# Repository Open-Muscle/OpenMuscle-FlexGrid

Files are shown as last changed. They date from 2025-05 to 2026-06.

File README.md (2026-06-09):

# 🧠 OpenMuscle-FlexGrid






OpenMuscle FlexGrid is a modular 60-sensor pressure-sensing platform designed for advanced forearm-based gesture tracking and biomechanical research.

This device is part of the [OpenMuscle](https://github.com/Open-Muscle) ecosystem and represents a leap forward from the original 12-sensor OM12 prototype by introducing high-density, flex-rigid PCBs and better sensor modularity.

### 📌 For documentation, firmware, and assembly guidance, visit the [OpenMuscle Hub](https://github.com/Open-Muscle/OpenMuscle-Hub).

---

## 🚀 Current revisions

**V4 (in development, 2026-06).** Ready for fab. Adds an on-device **microSD card socket** for local data logging, a **discrete RGB status LED** on three PWM channels, and a reoriented slimmer board profile that hugs the forearm. Carries forward the V3 power and interconnect architecture, but with the FFC tail width corrected from 11.1 mm to **10.5 mm** per the Wurth 687120183722 datasheet, the ADC matrix-row caps reduced from 2.2 uF to **100 pF** (resolves V3's 22 ms RC bleed in silicon rather than via post-fab cap removal), all resistors normalized to 0603, and several footprint cleanups. Manufacturing strategy: **single-side SMT at JLCPCB for an initial batch of 10 units, plus hand-soldering of bottom-side parts and through-hole connectors at home**. Not yet ordered, not yet brought up. Full status and pre-fab checklist in the [V4 README](KiCad/OM-FlexGrid%20V4/README.md).

**V3 (stable, 2026-05-13).** First revision to use a 20-pin ZIF FFC connector for the flex-to-rigid interconnect (Wurth 687120183722). Two boards populated and tested end-to-end. Sensor matrix delivers **clean single-cell press detection across all 60 sensors** with ~22% carryover decaying to noise floor within 3 columns. **V3 is the first FlexGrid generation usable as a real ML training data source.** Firmware: [FlexGridV3-Firmware v0.1.7](https://github.com/Open-Muscle/FlexGridV3-Firmware).

→ For V4 hardware files, see [`KiCad/OM-FlexGrid V4/`](KiCad/OM-FlexGrid%20V4/) and the [V4 README](KiCad/OM-FlexGrid%20V4/README.md). For V3 see [`KiCad/OM-FlexGrid V3/`](KiCad/OM-FlexGrid%20V3/) and the [V3 README](KiCad/OM-FlexGrid%20V3/README.md). The MicroPython firmware that runs on V3 (and will be ported to V4) lives at [FlexGridV3-Firmware](https://github.com/Open-Muscle/FlexGridV3-Firmware).

| Revision | Status | Notes |
|---|---|---|
| **V4** | 🟡 In development | microSD + RGB LED + slimmer reorient; 10.5 mm FFC tail; 100 pF ADC caps; not yet fabbed |
| **V3** | 🟢 Validated | 20-pin FFC interconnect, integrated stiffened FFC tail, ~140 Hz raw scan |
| V2 | 🟢 Tested | FFC connector exploration, fabric harness testing |
| V1 | 🟢 Tested | First production revision |
| V0 | 🟢 Tested | Original prototype |

→ Full cross-version comparison: [`KiCad/REVISIONS.md`](KiCad/REVISIONS.md). Manufacturing process used across revisions: [`docs/JLCPCB_WORKFLOW.md`](docs/JLCPCB_WORKFLOW.md).

---

## 🧬 Overview

FlexGrid uses a flexible pressure sensor matrix with rigid breakout interfaces to detect volumetric muscle contractions in real time. It supports:

- 🧠 Biomechanical signal analysis  
- 🦾 Prosthetics and exosuit research  
- 🎛️ Machine learning data pipelines  

---

## 📁 Hardware Design Files

Design files are organized by board type and version:

### 🔌 KiCad Schematics & PCB Layout

📂 [`KiCad/`](KiCad/) — all design files, organized by revision.

| Revision | Path | Description |
|---|---|---|
| **V4** (in dev) | [`KiCad/OM-FlexGrid V4/`](KiCad/OM-FlexGrid%20V4/) | microSD socket, RGB status LED, slimmer reorient, 10.5 mm FFC tail, 100 pF ADC caps. See [V4 README](KiCad/OM-FlexGrid%20V4/README.md). |
| **V3** (stable) | [`KiCad/OM-FlexGrid V3/`](KiCad/OM-FlexGrid%20V3/) | Validated. 20-pin ZIF FFC interconnect. See [V3 README](KiCad/OM-FlexGrid%20V3/README.md). |
| V2 | [`KiCad/OM-FlexGrid V2/`](KiCad/OM-FlexGrid%20V2/) | Tested. FFC exploration + fabric harness. See [V2 README](KiCad/OM-FlexGrid%20V2/README.md). |
| V1 | [`KiCad/OM-FlexGrid V1/`](KiCad/OM-FlexGrid%20V1/) | First production revision. |
| V0 | [`KiCad/OM-FlexGrid V0/`](KiCad/OM-FlexGrid%20V0/) | Original prototype. |

Each revision folder contains both the flex (`OM-FlexGrid-Flex/`) and rigid (`OM-FlexGrid-Rigid-PCB/`) board projects, plus their gerber bundles.

---

### 📦 Bill of Materials

BOMs live next to their KiCad project for each revision:

- **V4 Rigid (JLCPCB-ready):** [`KiCad/OM-FlexGrid V4/OM-FlexGrid-Rigid-PCB/jlcpcb/production_files/BOM-OM-FlexGrid-Rigid-PCB.csv`](KiCad/OM-FlexGrid%20V4/OM-FlexGrid-Rigid-PCB/jlcpcb/production_files/BOM-OM-FlexGrid-Rigid-PCB.csv) (LCSC part numbers, machine-readable, generated by the JLCPCB KiCad plugin). The hand-soldered parts list (microSD socket, FFC connector, battery JST, pin headers, plus single-side-strategy BOT-side SMT) is documented prose-style in the [V4 README](KiCad/OM-FlexGrid%20V4/README.md#hand-soldered-parts-full-list).
- **V3 Rigid:** [`KiCad/OM-FlexGrid V3/OM-FlexGrid-Rigid-PCB/OM-FlexGrid-Rigid-PCB.csv`](KiCad/OM-FlexGrid%20V3/OM-FlexGrid-Rigid-PCB/OM-FlexGrid-Rigid-PCB.csv) (KiCad export).
- **Flex (V3 and V4):** no electronic-component BOM. The flex tail integrates the FFC connector pads directly; the only off-board parts are the Velostat sheet and the mating Wurth 687120183722 connector populated on the rigid board.

Older revision BOMs are kept under [`BOM/`](BOM/) for history.

---

### 🛠 Assembly & Testing

Instructions for soldering, testing, and integrating the FlexGrid with ESP32-S3 firmware are in development. For now, please refer to the [OpenMuscle Hub](https://github.com/Open-Muscle/OpenMuscle-Hub) and follow updates on [YouTube Open Muscle](https://youtube.com/@openmuscle) or [TURFPTAx Youtube](https://youtube.com/@turfptax).

---

## 🤝 Contributions

We welcome improvements to sensor design, firmware, or real-world testing. Please fork the repo and submit pull requests!

---
**Open Muscle** is an open-source prosthetic sensor initiative designed for accessibility, innovation, and community collaboration.

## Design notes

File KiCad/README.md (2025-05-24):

"""
# FlexGrid KiCad Design Files

This folder contains the KiCad project files for the Open Muscle FlexGrid, a high-density, 60-sensor forearm band designed for advanced biometric data collection.

## 📁 Folder Contents

- `FlexGrid.kicad_pro` – KiCad project file  
- `FlexGrid.kicad_sch` – Schematic diagram  
- `FlexGrid.kicad_pcb` – PCB layout  
- `symbols/` – Custom schematic symbols  
- `footprints/` – Custom PCB footprints  
- `3dmodels/` – 3D models for components  
- `gerbers/` – Fabrication-ready Gerber files  
- `bom/` – Bill of Materials (CSV format)

## 🧠 About FlexGrid

FlexGrid is a 15x4 sensor matrix (totaling 60 sensors) integrated into a flexible PCB, utilizing an ESP32-S3 microcontroller for data acquisition and transmission. The design emphasizes:

- Ultra-thin 3mm sensor profile  
- High-density sensor arrangement for detailed muscle activity mapping  
- Compatibility with VR applications and prosthetic control systems  
- Open-source hardware principles for accessibility and collaboration

## 🛠️ Getting Started

1. **Install KiCad**: Ensure you have KiCad version 6.0 or later installed. [Download KiCad](https://www.kicad.org/download/)
2. **Open the Project**:
   - Launch KiCad.
   - Open the `FlexGrid.kicad_pro` file to access the full project.
3. **Explore the Design**:
   - View and edit the schematic in the Schematic Editor.
   - Inspect the PCB layout in the PCB Editor.
   - Utilize the 3D Viewer to visualize the assembled board.

## 🏭 Fabrication Files

The `gerbers/` directory contains all necessary files for PCB fabrication, including:

- Top and bottom copper layers  
- Solder mask layers  
- Silkscreen layers  
- Drill files  

These files are compatible with standard PCB manufacturing services.

## 📄 Bill of Materials

Located in the `bom/` directory, the BOM provides a comprehensive list of components, including:

- Reference designators  
- Component values  
- Footprints  
- Manufacturer part numbers  

This information facilitates component sourcing and assembly.

## 🤝 Contributing

We welcome contributions to improve and expand the FlexGrid project. To contribute:

1. Fork the repository.  
2. Create a new branch for your feature or fix.  
3. Commit your changes with clear messages.  
4. Submit a pull request detailing your modifications.

For major changes or proposals, please open an issue to discuss them first.

"""

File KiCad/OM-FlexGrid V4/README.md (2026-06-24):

# OM-FlexGrid V4

> **Status: BROUGHT UP 2026-06-23.** Boards arrived from JLCPCB; two units flashed with V4 MicroPython firmware and running end-to-end on the OpenMuscle discovery + subscribe protocol. Two hardware bugs surfaced during bring-up: USBLC6 ESD chip pinout reversed in the schematic (schematic fix landed; existing boards work with a 180-degree chip rotation), and the as-ordered IMU is a TOKMAS rebrand rather than genuine InvenSense as planned (driver auto-probes both variants; see [Bring-up findings](#bring-up-findings-2026-06-23) below). Total landed cost $341.84 for 10 units (~$35 per board for the JLC half; see [Cost breakdown](#cost-breakdown-10-unit-batch-june-2026) for per-unit details).

## 🎬 Build video

[**Unboxing & Setup: assembling the FlexGrid V4**](https://youtu.be/2tb6GW4FNU0) walks through hand-soldering the parts JLCPCB does not populate (ESP32-S3 module, CD74HC4067 mux, ZIF/FFC connector, USB-C, buttons, RGB LED), the USBLC6 180-degree rotation fix, and first power-on with the flex sensor mated. The microSD socket and haptic parts are deferred to a future video.

## 📄 Design documents (PDFs)

For people who want to review the design without opening KiCad:

### Rigid PCB

- 📐 [`FlexGridV4-Rigid-Schematic.pdf`](OM-FlexGrid-Rigid-PCB/FlexGridV4-Rigid-Schematic.pdf): full schematic, all sheets, all nets named
- 🟦 [`FlexGridV4-Rigid-PCB.pdf`](OM-FlexGrid-Rigid-PCB/FlexGridV4-Rigid-PCB.pdf): board layout

### Flex PCB

- 📐 [`FlexGridV4-Flex-Schematic.pdf`](OM-FlexGrid-Flex/FlexGridV4-Flex-Schematic.pdf): sensor matrix schematic
- 🟦 [`FlexGridV4-Flex-PCB.pdf`](OM-FlexGrid-Flex/FlexGridV4-Flex-PCB.pdf): flex layout including the stiffened FFC tail
- 🟧 [`FrontCopper_SolderMask.pdf`](OM-FlexGrid-Flex/FrontCopper_SolderMask.pdf): front-side copper + soldermask overlay (useful for sanity-checking the Velostat sensor cell exposures)

### What gets populated and what doesn't

The split between "JLCPCB assembles this" and "I hand-solder this after the boards arrive" is documented in [Hand-soldered parts (full list)](#hand-soldered-parts-full-list) below. tl;dr:

- **JLCPCB assembles all TOP-side SMT parts** (passives, regulators, charger, MUX-driver MOSFETs, MAX16054, USBLC6, IMU, CHRG LED, RGB LED, etc.)
- **You hand-solder everything else**: all BOT-side SMT (including U1 CD74HC4067 mux and U2 ESP32-S3 module), the microSD socket, the Wurth FFC connector, USB-C, and every through-hole pin header / JST. The per-designator table further down has each part listed by reference designator with solder-difficulty notes.

Fourth major revision of the Open Muscle FlexGrid wearable sensor platform. V4 builds on the V3 production baseline (which validated the FFC interconnect and proved the 60-cell matrix as a usable ML training data source) and adds on-device storage, a status indicator, and a slimmer board profile.

---

## Bring-up findings (2026-06-23)

Two boards from the 10-unit fab batch were flashed with V4 MicroPython firmware ([Open-Muscle/FlexGridV4-Firmware](https://github.com/Open-Muscle/FlexGridV4-Firmware), see its `BRINGUP.md` for step-by-step flashing instructions). Both ran the OpenMuscle discovery + subscribe protocol end-to-end against the PC `openmuscle web` app and the Android Connect client. Two hardware bugs surfaced during bring-up; both are documented here so future builders do not re-discover them.

### 1. USBLC6-2SC6 pinout reversed in schematic (FIXED)

The V4 KiCad schematic wired the USBLC6 with pin 2 on VBUS and pin 5 on GND. The actual chip pinout is the other way around (pin 2 = GND, pin 5 = VCC). With the silkscreen-correct placement, USB enumerates VBUS only (Windows reports "Device Descriptor Request Failed"), no COM port appears.

- **Workaround for the existing 10-unit batch:** rotate the USBLC6 chip 180 degrees from the silkscreen orientation during placement. The SOT-23-6 footprint is symmetric so the I/O pin pairs still route correctly, and VCC and GND land where they belong.
- **Schematic fix landed** in this repo. The next fab order will be correct without rotation.

### 2. IMU is a TOKMAS rebrand, not genuine InvenSense (DRIVER WORKAROUND)

The pre-fab checklist documented the IMU choice as genuine InvenSense ICM-42688-P (LCSC C1850418). The as-ordered BOM ended up with the cheaper TOKMAS rebrand (LCSC C54308212) instead. TOKMAS has the same general silicon spec but a different I2C address (0x36 / 0x37 instead of 0x68 / 0x69) and a different register map (data at 0x00-0x0D instead of 0x1F-0x2A).

- **Workaround:** [`lib/imu.py`](https://github.com/Open-Muscle/FlexGridV4-Firmware/blob/main/lib/imu.py) in the V4 firmware auto-probes both variants. Verified working on board #1: live accel + gyro at the expected rates.
- **Recommendation for the next fab order:** switch back to genuine InvenSense (C1850418) and retire the TOKMAS code path. The ~$11 per-chip savings cost a custom driver branch and ongoing maintenance.

### Firmware repo and bring-up guide

- Firmware: [Open-Muscle/FlexGridV4-Firmware](https://github.com/Open-Muscle/FlexGridV4-Firmware)
- Step-by-step flashing instructions: [`BRINGUP.md`](https://github.com/Open-Muscle/FlexGridV4-Firmware/blob/main/BRINGUP.md)
- One-shot flash script: `flash.py COM<port>` after pip-installing esptool 5.x + mpremote and downloading the MicroPython binary

---

## What is new in V4 vs V3

| Area | V3 | V4 | Why |
|---|---|---|---|
| **On-device storage** | None | **microSD socket** (SPI mode) | Local data logging and on-device model storage; lets the band run untethered for a session and offload later |
| **Status indication** | OLED only | **RGB status LED** (3-channel PWM) | Glance-tells "what is the band doing" without looking at the OLED; survives an OLED-off power state |
| **Power-on indicator** | None | Provided by the RGB LED's idle color | One fewer LED in the BOM; cleaner board |
| **Board orientation** | Original V3 layout | **Reoriented for slimmer bracelet fit** | Long axis aligned with the forearm; lower profile against the skin |
| **Diode footprints** | Mixed (D-SOD-123F seen on 1N5819 and 1N4007) | **Standardized on SOD-123** (1N4007W style) | Matches what LCSC actually stocks; avoids the V3 mid-design footprint mismatch we hit |
| **Resistor packages** | Mixed 0402 / 0603 | **All 0603** | Easier hand rework, broader LCSC stock, more forgiving for the prototype-quantity user |

What stays the same as V3: 60-sensor 15x4 Velostat matrix on the flex PCB, ESP32-S3-WROOM-1-N16R8 controller, CD74HC4067 mux, Wurth 687120183722 FFC interconnect, MAX16054 soft power, LTC4054-class charger, TPS7A03 LDO family (specific part TBD this revision), USB-C power and data, BAT54C diode-OR for VBUS-or-VBAT, ICM-42688-P IMU (genuine TDK or pin-compatible part, awaiting final LCSC stock decision).

---

## microSD card socket (NEW IN V4)

Wired in 1-bit SPI mode for simplicity and ESP32-S3 compatibility. SDIO 4-bit mode is not used; SPI is sufficient for logging sensor frames at the band's scan rates with margin.

| Pin name on socket | Wired to | Role in SPI mode |
|---|---|---|
| DATA0 (DAT0) | ESP32-S3 SPI MISO | data out of card |
| CMD | ESP32-S3 SPI MOSI | data in to card |
| CLK | ESP32-S3 SPI SCK | clock |
| DATA3 / CD | ESP32-S3 GPIO (CS) | chip select |
| VCC | 3V3 | power |
| GND, shield, mounting tabs | GND | return + mechanical |

### Connector

| Field | Value |
|---|---|
| Manufacturer P/N | Molex 5033981892 |
| LCSC P/N | **C428492** |
| Mount | Surface-mount, push-push, top side of rigid board |
| Hand-solder | **Yes, explicitly excluded from JLCPCB assembly** (see [Hand-soldered parts](#hand-soldered-parts) below) |

The microSD socket is intentionally hand-soldered after JLC assembly rather than included in the SMT run. Rationale: only one part, easy to solder, avoids a setup fee, and removes a parts-availability risk from the assembly order.

---

## RGB status LED (NEW IN V4)

Discrete common-cathode RGB LED in a 1.6 x 1.6 mm (0603-style) package, driven by three PWM-capable GPIOs through current-limiting resistors. Chosen over an addressable smart LED (WS2812 family) specifically for **zero quiescent current** when the LED is dark, which protects the 500 mAh battery's standby time.

### Wiring

| Channel | GPIO | Series resistor | Notes |
|---|---|---|---|
| Red | GPIO 40 | 330 ohm | adjust if too bright |
| Green | GPIO 41 | 330 ohm | |
| Blue | GPIO 42 | 330 ohm | |
| Common cathode | GND | n/a | shared return |

LCSC examples: C2827305-class 0603 common-cathode RGB. Final LCSC part number is recorded in the generated BOM at `jlcpcb/production_files/BOM-OM-FlexGrid-Rigid-PCB.csv`.

### Status palette (firmware target)

The exact palette is firmware-defined; the V4 hardware just provides the channels. Suggested defaults:

| State | Color | Pattern |
|---|---|---|
| Booting / Wi-Fi connecting | blue | slow breathe (1 Hz) |
| Idle, no peer | white | dim solid |
| Streaming sensor data | green | solid |
| Recording (paired with PC) | yellow | slow breathe |
| Sending predictions to hand | purple | solid |
| Sleeping / deep idle | off | n/a |
| Wi-Fi disconnected | orange | fast blink (3 Hz) |
| Error / sensor fault | red | fast blink |

---

## Layout reorientation

V4 rotates the long axis of the rigid board so it hugs the forearm rather than crossing it. The component placement was reworked around the new aspect ratio: power management clustered at one end, ESP32 and OLED at the other, microSD socket on the side that faces away from the skin so the user can pop a card in or out without removing the band.

---

## Footprint cleanup applied

Issues we hit during V3 design / V4 LCSC selection that are now fixed in V4:

- **1N5819 and 1N4007** previously used the `D_SOD-123F` footprint. LCSC primarily stocks the `1N5819W` and `1N4007W` variants in **SOD-123** (no `F` suffix). V4 swaps both diode footprints to plain SOD-123 to match what is actually available at the manufacturer.
- **Resistors** that the JLCPCB plugin's "auto-select alike" feature had silently downgraded to 0402 are all forced back to **0603**. This matches the LCSC Basic-tier inventory the design draws from and keeps hand rework feasible.
- **C9 (100 uF)** previously sat on an 0603 footprint that cannot physically host a 100 uF cap. Footprint upsized to match the chosen part.
- **MAX1 (MAX16054 soft-power controller)** footprint changed from SOT-23-6 to **TSOT-23-6** to match the LCSC part C79401 (MAX16054AZT+T ships in TSOT-23-6). The two packages share the same pad pitch and outline (the TSOT variant is just thinner), so a SOT-23-6 footprint would have accepted the part, but matching the footprint to the actual package is cleaner for downstream KiCad consumers. The schematic value also got cleaned up from `~` to `MAX16054` so the BOM and silkscreen identify it correctly.

---

## Known carry-forward concerns from V3

These items are present on the V4 board, were either copied from V3 unchanged or built in speculatively, and have **NOT been validated in the V4 configuration**. Documented here so future bring-up does not get blindsided.

### Haptic feedback circuit (built but untested)

V4 carries forward the haptic motor driver from V3 (IRLML2060 N-channel MOSFET on a haptic GPIO line, driving a small DC vibration motor through a header). The driver was placed on V3 and has been retained in V4 as a "just in case" feature for future user-feedback work, **but it has not been bench-tested in this configuration on any V3 board, and will arrive on V4 unvalidated**.

Treat haptic as an **optional / experimental feature** for now. If V4 bring-up needs haptic for a demo, expect a debug pass: gate-level on the MOSFET, motor selection, current draw at startup, and any required flyback protection.

The firmware should default the haptic GPIO to "off" and only enable it behind an explicit opt-in setting, so users running a standard recording or inference session do not get unexpected vibration.

### ADC matrix-row capacitors (C12, C13, C14, C15): RESOLVED

**Final decision: 100 pF (LCSC C14858, 0603, Basic tier).** Option 3 from the original analysis below.

The 100 pF value drops the RC time constant with each row's 10 kΩ pulldown from ~22 ms (V3 with 2.2 uF) to ~1 microsecond, well below the per-column ADC dwell time. Resolves the column-to-column bleed that V3 had to fix by removing the caps entirely, while preserving the high-frequency noise filtering at the ADC input. **No mid-bring-up rework needed on V4 if the math holds.**

For posterity, the original options considered were:

1. Leave the 2.2 uF parts in the JLC BOM, then physically remove them during V4 bring-up the same way V3 did. Wastes the per-board part cost; lowest cognitive risk.
2. Toggle C12 through C15 to BOM-OFF and POS-OFF in the JLCPCB plugin so JLC does not populate them. Hand-solder only if matrix bench-testing on a bare board shows they are needed for noise filtering. Matches V3 empirical outcome.
3. **Change the V4 value to 100 pF** (same 0603 footprint, new LCSC). Most engineering-correct; adds a small amount of rework. **Selected.**

V3's bring-up README documents the original symptom (22 ms RC bleed at 2.2 uF, ~9x signal improvement after physical removal).

---

## Manufacturing (JLCPCB)

V4 was prepared for JLCPCB SMT assembly using the [`Bouni/kicad-jlcpcb-tools`](https://github.com/Bouni/kicad-jlcpcb-tools) KiCad plugin. The full workflow we use across revisions is captured at `docs/JLCPCB_WORKFLOW.md` in this repository.

### Strategy: single-side SMT + hand assembly

The first V4 batch is 10 units. We chose **single-side SMT assembly** at JLCPCB (top side only) over double-side assembly. Tradeoff:

- **Saves money** on JLC's double-side setup fee, roughly $25 to $50 per order at this quantity
- **Costs time** at the hand-solder bench: every bottom-side SMT part has to be reflowed at home, including the ESP32-S3-WROOM-1 module
- Acceptable for a prototyping batch of 10 because the time investment is one-off; future production runs can revisit this when component placement is stable enough to justify the double-side setup

Required hand-assembly equipment for this strategy:
- Hot air rework station or solder paste + stencil + reflow plate, specifically for the ESP32-S3-WROOM-1 module's thermal pad
- Fine-tipped iron, liquid flux, solder wick, 10x or better magnification, for the TSSOP-24 mux and 0402 / 0603 BOT-side passives
- Standard through-hole iron technique for the pin headers, battery JST, OLED connector, USB-C, and Wurth FFC

### Generated output files (in `OM-FlexGrid-Rigid-PCB/jlcpcb/`)

```
jlcpcb/
|-- gerber/                                       individual Gerber + drill files
`-- production_files/
    |-- GERBER-OM-FlexGrid-Rigid-PCB.zip          upload this zip directly to JLCPCB
    |-- BOM-OM-FlexGrid-Rigid-PCB.csv             BOM with LCSC part numbers
    `-- CPL-OM-FlexGrid-Rigid-PCB.csv             component placement / pick-and-place
```

The BOM and CPL **only contain parts JLC will assemble**. Everything we hand-solder is excluded at the plugin level (BOM-OFF and POS-OFF), which keeps the manufacturer's view of the BOM clean and matches the physical reality of the assembled board they ship.

### Hand-soldered parts (full list)

All bottom-side SMT plus every through-hole part. Excluded from the JLC BOM and CPL by toggling BOM-OFF and POS-OFF in the plugin. Buy these separately and populate them after the JLC-assembled boards arrive.

**Bottom-side SMT (excluded for single-side cost saving):**

| Designator | Part | Footprint | Solder difficulty |
|---|---|---|---|
| **U2** | ESP32-S3-WROOM-1-N16R8 | Module, castellated edges + thermal pad | **Hard**: hot air rework or stencil reflow only |
| **U1** | CD74HC4067M | TSSOP-24, 0.65 mm pitch | Medium: fine iron + flux + wick |
| C9 | 100 uF cap | 0603 (or larger if footprint was upsized) | Easy |
| D4 | 1N4007W | SOD-123 | Easy |
| Q1 | IRLML2060 | SOT-23 | Easy |
| R10, R11 | 10 kΩ | 0603 | Easy |
| J9 | microSD socket (Molex 5033981892, LCSC C428492) | Push-push SMT | Easy with patience |

**Through-hole connectors (JLC standard SMT assembly does not cover these regardless of side):**

| Designator | Part | Notes |
|---|---|---|
| J1 | Programming / debug pin header | 6-pin 1x06 vertical |
| J2 | Battery JST terminal | 2-pin through-hole |
| J3 | Wurth 687120183722 FFC connector (rigid side) | Sourced direct from Mouser (P/N 710-687120183722). Würth not consistently available at LCSC |
| J4 | USB-C receptacle (HRO PE-C-31-M-12 or equivalent) | SMT but explicitly hand-soldered for this batch |
| J5, J6, J7 | Pin headers / sockets | Various, all through-hole |
| SCRN1 | OLED interface (4-pin pin header) | Through-hole |

**Mounting holes (H1 through H4) are virtual** in the BOM sense; they have BOM-OFF and POS-OFF set because there is no component to source or place. They exist on the PCB as physical M2 mounting positions only.

The authoritative per-designator list lives in the schematic and the JLCPCB plugin's UI (any designator with BOM-toggle and POS-toggle OFF). The generated BOM and CPL CSVs reflect those exclusions.

### Cost breakdown (10-unit batch, June 2026)

Real numbers from the V4 fab order placed on 2026-06-12. Use these as a starting estimate for budgeting your own build; LCSC prices and JLC fees move month to month.

**JLCPCB landed cost (rigid + flex, both boards together):**

| Line item | Total | Per board (10 units) |
|---|---|---|
| Merchandise (4-layer rigid PCB + flex PCB + single-side SMT assembly) | $204.72 | $20.47 |
| Shipping (DHL to Texas) | $47.20 | $4.72 |
| Customs duties + taxes | $71.66 | $7.17 |
| Sales tax | $18.26 | $1.83 |
| **Grand total at checkout** | **$341.84** | **~$35** |

So the JLC half of the build lands at **~$35 per assembled board**: top-side SMT populated, ready for the hand-solder add-ons.

**Hand-solder add-on parts (rough qty-10 prices, source noted):**

| Part | Source | Per-unit (qty 10-20) |
|---|---|---|
| ESP32-S3-WROOM-1-N16R8 module (U2) | LCSC | ~$5.00 |
| Wurth 687120183722 FFC connector (J3, rigid side) | Mouser (P/N 710-687120183722) | ~$2.50 |
| microSD push-push socket (J9) | LCSC C428492 | ~$1.00 |
| USB-C receptacle (J4) | LCSC | ~$1.00 |
| CD74HC4067M 16-channel mux (U1) | LCSC | ~$0.70 |
| Pin headers, JST battery terminal, OLED interface (J1, J2, J5, J6, J7, SCRN1) | LCSC | ~$1.00 combined |
| BOT-side passives (C9, D4, Q1, R10, R11) | LCSC | ~$0.50 combined |
| **Hand-solder add-on subtotal** | | **~$12** |

**External parts not on either BOM (per band):**

| Part | Per-unit |
|---|---|
| SSD1306 128 x 32 OLED display module | ~$3 |
| 500 mAh LiPo battery | ~$6 |
| Cloth bracelet housing (Velcro, fabric, elastic, anti-slip tape) | varies, ~$2 to $5 |

**Estimated total per complete wearable: ~$55 to $60.** That's the JLC landed cost, plus the hand-solder add-ons, plus the display and battery. Cost drops meaningfully above ~50 units because JLC's setup fees amortize and LCSC reel pricing kicks in.

What this does NOT include: the build labor (~30 minutes per board of hand-soldering once the workflow is dialed in), the tooling cost (hot-air station, microscope, stencil), or the dev iterations that got us to a working V4.

---

## Pre-fab checklist

### Resolved this pass

- [x] **IMU footprint fixed.** IC1 (ICM-42688-P) was swapped from a custom `IIM42352` named footprint to KiCad's standard `Package_LGA:LGA-14_3x2.5mm_P0.5mm_LayoutBorder3x4y`. POP now shows green; JLC can place the part with the chosen LCSC.
- [x] **Manufacturing strategy locked.** Single-side SMT at JLCPCB for the first 10 units, plus hand assembly of every BOT-side part and every through-hole part. See [Manufacturing](#manufacturing-jlcpcb) above.
- [x] **TPS7A03 LDO chosen.** C2873330 (Texas Instruments TPS7A0333DBVR, 3.3 V output, SOT-23-5, ~3000 stock at LCSC).
- [x] **STC4054GR charger chosen.** C262930 (ST Microelectronics, pin-compatible with the original LTC4054).
- [x] **CHRG LED swap.** Replaced the original Extended-tier C72043 (stock = 1) with C2297 (Basic tier, > 3M stock).
- [x] **Footprint cleanup applied:** 1N5819 and 1N4007 standardized on SOD-123, all resistors forced to 0603, C9 footprint upsized to fit the chosen 100 uF cap, MAX1 (MAX16054) footprint moved to TSOT-23-6.
- [x] **ADC matrix-row caps C12-C15 changed to 100 pF.** Resolves the V3 column-bleed risk in silicon; no mid-bring-up rework needed. New LCSC: C14858 (Basic tier).

### Done before fab submission

- [x] **V4 Flex PCB FFC tail width fixed.** Bumped from 11.1 mm to 10.5 mm per the Wurth 687120183722 datasheet; the +67.6 deg horizontal-banana rotation was applied via `scripts/prep_flex_svgs.py` and re-imported into the V4 Flex Edge.Cuts layer.
- [x] **Final BOM scan completed.** RGB LED swapped to ASMB-UTF2-0E20B (C7077610, Avago PLCC-6 RGB, 100 in stock, $0.56) replacing the original 1615 part. IMU was specified as genuine InvenSense ICM-42688-P (C1850418, $14.19, 3358 in stock); however, **the as-ordered BOM ended up with the TOKMAS rebrand (C54308212)** rather than the genuine part. Documented in [Bring-up findings](#bring-up-findings-2026-06-23). Next fab should re-select C1850418.
- [x] **JLCPCB order submitted 2026-06-12.** $341.84 total landed cost. "Confirm Production file" toggled ON; PCB Remark field carries explicit stiffener-side instructions (FR-4 0.2 mm on B.Cu side, 10.5 x 8 mm under the FFC contact pads per User.1 layer).
- [x] **Responded to JLC's production-file confirmation email.** Order proceeded; boards arrived 2026-06-23.
- [x] **Parts for hand assembly ordered and received.** ESP32-S3-WROOM-1, CD74HC4067M, USB-C, Wurth FFC, microSD socket, headers all in inventory; two boards built end-to-end.
- [x] **Boards brought up.** See [Bring-up findings](#bring-up-findings-2026-06-23). Two HW bugs surfaced (USBLC6 schematic-fixed; TOKMAS IMU driver workaround).
- [x] **Flag haptic as experimental in firmware.** Firmware defaults `haptic_enabled` to false in `lib/settings_manager.py`; explicit opt-in only.

### Still open

- [ ] **Mechanical / 3D fit check** against the bracelet enclosure (3D STEP at `OM-FlexGrid-Rigid-PCB.step`). Two bring-up boards are loose; first complete wearable assembly still pending.
- [ ] **Next-fab BOM changes** to land before the second batch:
    - Swap TOKMAS IMU back to genuine InvenSense (C1850418).
    - Verify the USBLC6 schematic fix produces a correct CPL on the next fab.
    - Reconfirm RGB LED, LDO, charger LCSC parts are still in stock at the same tier.
- [ ] **Distribute remaining boards** to collaborators (8 boards spare; Christopher gets 2+ for prosthetics socket integration work).

---

## File layout

```
OM-FlexGrid V4/
|-- OM-FlexGrid-Flex/                        Flex PCB (15x4 sensor matrix + FFC tail)
|   |-- OM-FlexGrid-Flex.kicad_pro           KiCad project
|   |-- OM-FlexGrid-Flex.kicad_sch           Schematic
|   |-- OM-FlexGrid-Flex.kicad_pcb           PCB layout (flex + integrated FFC tail)
|   |-- FlexGridV4-Flex-Schematic.pdf        Reviewable schematic PDF
|   |-- FlexGridV4-Flex-PCB.pdf              Reviewable layout PDF
|   |-- FrontCopper_SolderMask.pdf           Sensor cell overlay PDF
|   |-- V4CurveCutout.svg                    Fusion 360 source: flex body outline
|   |-- FFC-Stiffener.svg                    Fusion 360 source: FFC tail stiffener
|   |-- V4-EdgeCuts-for-KiCad.svg            Processed: import to Edge.Cuts
|   `-- V4-Stiffener-for-KiCad.svg           Processed: import to Stiffener user layer
`-- OM-FlexGrid-Rigid-PCB/                   Rigid controller board
    |-- OM-FlexGrid-Rigid-PCB.kicad_pro      KiCad project
    |-- OM-FlexGrid-Rigid-PCB.kicad_sch      Schematic (24K lines)
    |-- OM-FlexGrid-Rigid-PCB.kicad_pcb      PCB layout
    |-- FlexGridV4-Rigid-Schematic.pdf       Reviewable schematic PDF
    |-- FlexGridV4-Rigid-PCB.pdf             Reviewable layout PDF
    |-- OM-FlexGrid-Rigid-PCB.csv            BOM (KiCad-exported)
    |-- OM-FlexGrid-Rigid-PCB.step           3D model
    |-- OM-FlexGrid-Rigid-V4-Gerber/         Standalone Gerber export
    |-- OM-FlexGrid-Rigid-V4-Gerber.zip      Standalone Gerber zip
    |-- OmFlexGridArtV4.svg                  Front silkscreen artwork
    |-- jlcpcb/                              JLCPCB plugin output (use these for ordering)
    |   |-- gerber/
    |   `-- production_files/
    |       |-- GERBER-OM-FlexGrid-Rigid-PCB.zip
    |       |-- BOM-OM-FlexGrid-Rigid-PCB.csv
    |       `-- CPL-OM-FlexGrid-Rigid-PCB.csv
    `-- OM-FlexGrid-Rigid-PCB-backups/       KiCad auto-rotated backups from this design session
```

---

## Related work

- **V3 status and bring-up findings:** `../OM-FlexGrid V3/README.md`
- **JLCPCB plugin workflow (generic, applies to all revisions):** `../../docs/JLCPCB_WORKFLOW.md`
- **Cross-revision comparison table:** `../REVISIONS.md`
- **V4 Firmware:** [Open-Muscle/FlexGridV4-Firmware](https://github.com/Open-Muscle/FlexGridV4-Firmware) (active; includes TOKMAS IMU support, ssd1306 driver vendored, `flash.py` one-shot bring-up, BRINGUP.md guide)
- **V3 Firmware:** [Open-Muscle/FlexGridV3-Firmware](https://github.com/Open-Muscle/FlexGridV3-Firmware) (shipping V3 reference; V4 firmware was forked from this)
- **Cross-device protocol spec:** [`PROTOCOL.md`](https://github.com/Open-Muscle/OpenMuscle-Hub/blob/main/PROTOCOL.md) in OpenMuscle-Hub (wire format, discovery, subscribe semantics, multi-device data model)

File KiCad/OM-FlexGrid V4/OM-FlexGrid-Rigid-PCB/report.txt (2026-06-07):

Placement file: 'D:\MT2-TX\OneDrive - TURFPTAx\Documents\GitHub\OpenMuscle-FlexGrid\KiCad\OM-FlexGrid V4\OM-FlexGrid-Rigid-PCB\OM-FlexGrid-Rigid-PCB-all.pos'.
Info: Component count: 42.
Info: Done.

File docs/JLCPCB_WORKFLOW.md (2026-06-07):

# JLCPCB Assembly Workflow (KiCad + Bouni Plugin)

How OpenMuscle hardware revisions get from a routed KiCad project to a JLCPCB order. The procedure is the same for every board (Flex, Rigid, future revisions); only the specific LCSC parts change.

This document captures the workflow we use today. It is generic enough to apply to any V4+ revision of the FlexGrid or other Open Muscle boards.

---

## Toolchain

| Component | What it does |
|---|---|
| **KiCad 8.x** | Schematic capture + PCB layout (you already have this) |
| **`kicad-jlcpcb-tools` plugin** | LCSC part search, LCSC-number tagging on components, BOM + CPL + Gerber generation in JLCPCB-friendly format |
| **JLCPCB web ordering page** | https://jlcpcb.com/ (where the generated files actually get uploaded) |

### Plugin install (one-time per machine)

The plugin is **not** in KiCad's official Plugin and Content Manager repository, so two install paths:

**Option A: Install from a release zip (recommended)**

1. Download the latest release from https://github.com/Bouni/kicad-jlcpcb-tools/releases (looks like `KiCadJLCPCBTools.zip` or similar)
2. KiCad main window → **Tools → Plugin and Content Manager**
3. Click **Install from File...** at the bottom
4. Pick the downloaded zip
5. Apply Pending Changes, restart KiCad

**Option B: Add Bouni's PCM repository for auto-updates**

1. PCM dialog → **Manage...** (top right)
2. Add a new repository:
   - Name: `Bouni's repo`
   - URL: `https://raw.githubusercontent.com/Bouni/bouni-kicad-repository/main/repository.json`
3. Switch the repository dropdown to "Bouni's repo"
4. Search `jlcpcb`, install the plugin, restart KiCad

After install: the plugin appears as a button in the **PCB Editor toolbar** (not the schematic editor). Also accessible at **Tools → External Plugins → JLCPCB Tools**.

---

## Per-revision workflow

The 5 phases below run in order for every new revision. Each phase is a checkpoint; don't skip ahead.

### Phase 1: tag LCSC parts on every component

Open the PCB editor for the board you are about to fab. Click the JLCPCB Tools button. A side panel opens listing every component on the board, color-coded:

- **Green** = LCSC part is assigned, BOM and POS toggled on
- **Red** = no LCSC part yet, needs attention
- **Yellow / partial** = mixed state (some flags off)

For each red row:

1. Click the row in the panel
2. Click **Assign LCSC number**
3. The plugin opens a search dialog into LCSC's catalog
4. Search by part value (e.g. `100nF 0603` for a cap, or by exact MFR name like `BSS84`)
5. **Check all three tier boxes**: Basic, Preferred, Extended
6. Also check **Only show parts in stock**
7. Look at the **Package** column to verify it matches your KiCad footprint
8. Pick the row with the best stock + tier
9. Click **Select part**

The LCSC number is now associated with that component.

### Phase 2: handle hand-soldered parts

Any part you intend to hand-solder after JLC assembly (microSD socket, FFC connector, pin headers, battery JST, through-hole anything) should be **excluded from both BOM and POS** so JLC neither sources nor places it.

1. Select the row in the plugin panel
2. Click **Toggle BOM POS** (or Toggle BOM + Toggle POS individually)
3. The BOM and POS columns should flip to red X marks
4. Leave the LCSC field empty or as-is; the exclusion is what matters

A separate column called **POP** (Place On PCB) shows whether JLC's machines can actually assemble the part. POP = X means the part is sourceable but not assembleable; fix by picking a different LCSC part or accept the part as hand-soldered.

### Phase 3: tier and stock sanity pass

Before generating, scan the panel for risk patterns:

- Count rows with **Type = Extended**. Each one adds **$3 setup fee** to your order. Worth checking if a Basic-tier equivalent exists.
- Look for rows with **Stock < 1000**. Those parts can go out of stock between now and when JLC places the order. Substitute if possible.
- Spot-check **value vs LCSC Params**. The schematic value (e.g. "10k") should match the LCSC part description (e.g. "10kΩ ±1% 0603"). Mismatches are silent assembly bugs.

### Phase 4: save and export

1. **Save mappings** (button on the right side of the plugin panel). This writes your LCSC choices into the plugin's database for re-use across projects.
2. **Export to schematic**. This writes the LCSC field into each component's symbol in the schematic file.
3. Open the **Schematic Editor** and press **Ctrl+S** to actually save the schematic file (this is the step people miss; the export-to-schematic only marks the file as modified)

### Phase 5: generate fab files

Back in the PCB editor JLCPCB plugin panel:

1. Click **Generate fabrication files for JLCPCB** (top-left button)
2. The plugin creates a `jlcpcb/` directory next to your `.kicad_pcb` file containing:

```
jlcpcb/
|-- gerber/                                       individual Gerber + drill files
`-- production_files/
    |-- GERBER-<projectname>.zip                  what you upload
    |-- BOM-<projectname>.csv                     BOM with LCSC numbers
    `-- CPL-<projectname>.csv                     pick-and-place coordinates
```

3. **Open and verify** the BOM and CPL CSVs:
   - BOM: every row should have a non-empty LCSC column (Cxxxxx format)
   - BOM: hand-soldered parts should be **absent** from the list
   - CPL: same set of designators as the BOM
   - Spot-check one or two rotation values against the part's datasheet pin-1 orientation (the plugin applies JLC's known rotation corrections automatically; this is a sanity check, not a fix)

---

## Uploading to JLCPCB

Order page: https://jlcpcb.com/quote

1. Drag the `GERBER-<projectname>.zip` into the gerber upload field
2. JLCPCB reads the gerbers and shows a board preview. Verify board outline, layer count, dimensions, drill positions.
3. Choose your PCB options (layers, thickness, color, surface finish, etc.)
4. Toggle on **PCB Assembly**. Pick:
   - **Assembly Side**: single-side (TOP) by default. Choose double-side only if you have BOT components that need SMT placement.
   - **Tooling holes**: per JLCPCB's recommendation
   - **Confirm parts placement**: yes (gives you a final visual review)
5. Upload the **BOM** CSV when prompted
6. Upload the **CPL** CSV when prompted
7. JLC processes the files. Within ~30 minutes you receive a **parts placement preview** email asking you to confirm rotations and positions before they cut metal.

**Always review the placement preview.** This is where rotation errors are caught (e.g., a SOT-23 placed 180 degrees rotated would short power to ground). If anything looks wrong, the plugin's rotation correction is the most common cause; adjust in KiCad, regenerate, re-upload.

---

## BOM presentation in a public repo

A common ask for an open-hardware project: the repo's BOM should be readable by people who are not going to fab the board, while the BOM JLC actually uses needs to be machine-readable and accurate.

Two-file pattern:

| File | Audience | Source of truth? |
|---|---|---|
| `jlcpcb/production_files/BOM-<projectname>.csv` | JLCPCB | **Yes**, this is what they assemble from. Do not hand-edit; regenerate from the plugin. |
| Optional `BOM/Hand-Solder-Notes.md` or repo README section | Humans browsing the repo | Human-friendly notes about what is hand-soldered and why |

The plugin-generated BOM **only includes parts JLC will assemble**, which is what you want for the manufacturer. Hand-soldered parts get documented separately as prose, with the canonical list living in the revision's README (e.g. `KiCad/OM-FlexGrid V4/README.md` → "Hand-soldered parts").

---

## Tips earned the hard way

- **Avoid "Auto-select alike"** as a bulk action. It groups parts by footprint, not value, and will happily tag every 0603 resistor with the same LCSC number regardless of resistance. Tag manually one value at a time.
- **Check the Package column on every search result.** Same MFR number can come in different packages; SOT-23 vs SOT-323 vs TSOT-23 look similar in name but have different pad geometry.
- **TSOT-23-6 is pad-compatible with SOT-23-6**, same pitch + same pad layout, just thinner profile. A common gotcha when a part is only available in TSOT.
- **SOD-123FL is NOT pad-compatible with SOD-123**, different pad geometry. Check before assuming.
- **Basic and Preferred tiers have no setup fee**, Extended has $3 per unique part. A board with 5 Extended-tier parts costs $15 more in setup than a board with 5 Basic equivalents. Worth optimizing for.
- **The "Save mappings" plugin database** remembers your choices across projects. After you have tagged a bunch of common values once, future projects auto-suggest the same LCSC parts.
- **POP = X in the plugin** means JLC can source the part but cannot auto-place it. Pick a different LCSC part; do not just ignore the warning, the assembly will not happen.
- **For double-side assembly**, JLC charges meaningfully more than single-side. If your BOT side has only one or two SMD parts, consider moving them to TOP in the next revision.

---

## Workflow checklist (copy this into the revision's commit message)

```
[ ] Every component tagged with an LCSC part number (or explicitly excluded)
[ ] All hand-soldered parts have BOM and POS toggled OFF
[ ] No POP = X warnings remaining (or accepted as hand-soldered)
[ ] Tier mix is acceptable (counted Extended-tier parts, weighed setup cost)
[ ] Stock levels checked (no parts at < 1000 in stock)
[ ] Mappings saved + exported to schematic + schematic saved
[ ] Fab files regenerated AFTER schematic save
[ ] BOM CSV manually inspected (LCSC values present, hand-solder parts absent)
[ ] CPL CSV manually inspected (designators match BOM, rotations sane)
[ ] 3D STEP exported for mechanical fit check (if board lives in an enclosure)
```

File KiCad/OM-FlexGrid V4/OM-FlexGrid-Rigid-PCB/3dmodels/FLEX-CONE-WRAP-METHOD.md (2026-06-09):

# Wrapping a Flex PCB onto its Cone in Blender (without the spiral)

How we wrapped the OpenMuscle FlexGrid flex PCB onto a tapered (forearm) cone in
Blender so that every cross section is a true flat circle, with no spiral and no
twist. Written after a long debugging session so it can be reproduced quickly.

## TL;DR

The flat flex was cut as a **curved crescent**, which is the **unrolled
(developed) shape of a cone** (an annular sector). The fix is to **roll it back
up around the crescent's own center of curvature (the cone apex)**, using the
inverse cone-development mapping. Wrapping it any other way (like a rectangle,
or with Blender's Curve modifier) produces a spiral.

## The trap (what does NOT work)

1. **Treating the flex as a rectangle**: mapping length to wrap-angle and width
   to the axis. This only works if the flat piece is a rectangle (rolls into a
   cylinder). A crescent rolled this way spirals.
2. **Blender Curve modifier (wrap along a circle)**: on a closed circular path
   it accumulates a built-in frame rotation. Measured twist on our part was
   about 357 degrees (a full barber pole). Do not use it for a closed wrap.
3. **Simple Deform > Bend**: on a flat sheet it curls the sheet in its own
   plane (a flat coil), not into an upright tube.

## The key realization

Look at the flat flex from the top. If the outline is a **crescent / banana
(curved long edges)**, it is an annular sector, i.e. a cone development. A clean
circle fit to one of its long edges will have a tiny residual (ours was
0.13 mm), which confirms the edge is a true arc and gives you the apex.

## The correct method

1. View the flat flex from top; confirm it is a crescent.
2. Fit a circle to one clean long edge (Kasa least squares). The center is the
   cone apex `O`; bin by X and take the min-Y (or max-Y) vertex per bin so you
   fit a single clean edge arc, not the filled region.
3. For every vertex compute polar coords about `O` in the flat plane:
   - `rho = distance from O`
   - `phi = angle about O`
4. Let `alpha = phi span` (total sweep of the sector) and `phi0 = mid phi`.
   For a band that closes fully around (360 degrees):
   - `sin(beta) = alpha / (2*pi)`  (beta = cone half-angle)
   - `cos(beta) = sqrt(1 - sin(beta)^2)`
5. Map each vertex onto the cone (axis along world Y):
   - wrap angle `theta = (phi - phi0) / sin(beta)`
   - cone radius `r = rho*sin(beta) + (z - z_neutral)`  (the z term re-adds flex thickness radially)
   - axial position `Y = rho*cos(beta)` (then center it)
   - world position `= ( r*sin(theta), Y, r*cos(theta) )`

Because `theta` depends only on `phi` and `Y`/`r` depend only on `rho`, a row of
constant `rho` becomes a perfect flat circle and a line of constant `phi`
becomes a straight meridian. No twist by construction.

## Diagnostics that actually tell the truth

- **Ring test (is it a circle?)**: take vertices at constant ORIGINAL world-Y
  (a true ring). Measure spread in world-Y (axial drift = spiral) and spread in
  radius (circle error). Clean wrap: both near zero. Ours: worldY 0.03 mm,
  radius 0.16 mm.
- **Edge circle fit residual**: confirms the flat edge is a real arc (annular
  sector). Low residual = it is a cone development.

Pitfalls that gave false readings during debugging:
- Grouping diagnostic vertices by LOCAL Y on a branched mesh (local Y is not
  constant-world-Y). Always group by world coordinates.
- `atan2` wraps at +/-180 degrees; a twist column sampled right at the seam
  reads a huge or tiny spread that is meaningless. Sample away from the seam.
- A finite selection window in X converts to an angle (delta_x / R), which looks
  like "twist." Account for the window width before believing a twist number.

## Results for OM-FlexGrid V4

- Fitted apex `O` (flat plane): about (1.3 mm, 609.0 mm); bottom-edge arc radius
  639.9 mm; fit residual 0.13 mm.
- The flex's TRUE cone: radius 42.9 to 47.4 mm (about 86 to 95 mm diameter),
  about 60 mm tall, half-angle 4.25 degrees, sweep alpha 26.6 degrees, wraps a
  full 360 degrees.
- Note: the cone first placed in Fusion (R 37.9 to 51.8, 102 mm, 7.7 degrees) did
  NOT match the flex's development. The flex itself tells you the real cone via
  the edge fit. If you want a cone object to sit under the flex, build it to the
  TRUE numbers above (or re-derive from the flex each time).

## Reusable Blender script

Run in Blender's scripting workspace (or via the Blender MCP). Assumes the flat
flex object is named `FlexPCB`, lies roughly flat, and that you want the cone
axis along world Y. Produces a new object `FlexPCB_wrapped`.

```python
import bpy, math, mathutils, bmesh
M = mathutils

SRC_NAME = "FlexPCB"          # flat flex (the crescent)
OUT_NAME = "FlexPCB_wrapped"  # result

src = bpy.data.objects[SRC_NAME]
P = [src.matrix_world @ v.co for v in src.data.vertices]
zs = [p.z for p in P]
z_neutral = (min(zs) + max(zs)) / 2

# --- 1) fit a circle (apex O) to one clean long edge ---
xs = [p.x for p in P]
xmin, xmax = min(xs), max(xs)
NB = 60
edge = {}
for p in P:                     # bottom edge = min-Y vertex per X bin
    b = int((p.x - xmin) / (xmax - xmin + 1e-9) * NB)
    if b not in edge or p.y < edge[b].y:
        edge[b] = p

def kasa(pts):                  # algebraic circle fit -> (cx, cy, R)
    n = len(pts)
    ex = [q.x for q in pts]; ey = [q.y for q in pts]
    z = [ex[i]**2 + ey[i]**2 for i in range(n)]
    Sx=sum(ex); Sy=sum(ey); Sxx=sum(a*a for a in ex); Syy=sum(a*a for a in ey)
    Sxy=sum(ex[i]*ey[i] for i in range(n))
    Sxz=sum(ex[i]*z[i] for i in range(n)); Syz=sum(ey[i]*z[i] for i in range(n)); Sz=sum(z)
    m=[[Sxx,Sxy,Sx,-Sxz],[Sxy,Syy,Sy,-Syz],[Sx,Sy,n,-Sz]]
    for i in range(3):
        pv=m[i][i]
        for j in range(i+1,3):
            f=m[j][i]/pv
            for k in range(4): m[j][k]-=f*m[i][k]
    C=m[2][3]/m[2][2]; B=(m[1][3]-m[1][2]*C)/m[1][1]; A=(m[0][3]-m[0][1]*B-m[0][2]*C)/m[0][0]
    cx=-A/2; cy=-B/2
    return cx, cy, math.sqrt(max(0, cx*cx+cy*cy-C))

Ox, Oy, Redge = kasa(list(edge.values()))

# --- 2) polar coords about O, sector sweep, cone half-angle ---
rho = [math.hypot(p.x-Ox, p.y-Oy) for p in P]
phi = [math.atan2(p.y-Oy, p.x-Ox) for p in P]
alpha = max(phi) - min(phi)
phi0 = (min(phi) + max(phi)) / 2
sinb = alpha / (2*math.pi)
cosb = math.sqrt(max(0, 1 - sinb*sinb))
hmid = (min(r*cosb for r in rho) + max(r*cosb for r in rho)) / 2

# --- 3) roll up onto the cone (axis = world Y) ---
old = bpy.data.objects.get(OUT_NAME)
if old: bpy.data.objects.remove(old, do_unlink=True)
dup = src.copy(); dup.data = src.data.copy(); dup.name = OUT_NAME
bpy.context.scene.collection.objects.link(dup)
mw = dup.matrix_world.copy(); mwi = mw.inverted()
me = dup.data
for v in me.vertices:
    w = mw @ v.co
    rp = math.hypot(w.x-Ox, w.y-Oy)
    ph = math.atan2(w.y-Oy, w.x-Ox)
    th = (ph - phi0) / sinb
    r  = rp*sinb + (w.z - z_neutral)
    Y  = rp*cosb - hmid
    v.co = mwi @ M.Vector((r*math.sin(th), Y, r*math.cos(th)))
me.update()
bm = bmesh.new(); bm.from_mesh(me)
bmesh.ops.recalc_face_normals(bm, faces=bm.faces); bm.to_mesh(me); bm.free()

print("apex O (mm): %.1f, %.1f  edge R %.1f" % (Ox*1000, Oy*1000, Redge*1000))
print("cone half-angle %.2f deg, R %.1f..%.1f mm, wraps %.0f deg" % (
    math.degrees(math.asin(sinb)), min(rho)*sinb*1000, max(rho)*sinb*1000,
    math.degrees(alpha/sinb)))
```

## Notes and gotchas

- This is a destructive bake. Keep the flat `FlexPCB` as a hidden backup so you
  can re-run with different parameters.
- It is not a live modifier. Blender's deform modifiers cannot do this exact
  mapping without the twist, so a bake (or a Geometry Nodes equivalent) is the
  clean route. Re-baking is fast.
- If the flex should stay flat near the rigid board and only wrap past it, mask
  the roll-up by the vertex's `phi` (or original X) range.
- To add a small standoff so the flex sits just proud of the cone surface, add a
  constant to `r` (for example `+ 0.0005` for 0.5 mm).
- The two long edges of a true annular sector are concentric. If one edge fits
  cleanly and the other does not, the bad fit is usually a connector tail or
  outline feature, not the development. Fit the clean edge.

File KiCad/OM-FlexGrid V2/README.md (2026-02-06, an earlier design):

# OM-FlexGrid V2

The second major revision of Open Muscle's FlexGrid wearable sensor platform. V2 includes improvements to both the flexible sensor matrix and rigid controller board.

---

## Overview

V2 consists of two paired PCBs:

| Board | Description |
|---|---|
| **OM-FlexGrid-Flex** | Flexible PCB with 15×4 Velostat sensor matrix (60 sensors) |
| **OM-FlexGrid-Rigid-PCB** | Rigid controller with ESP32-S3, power management, display, and interfaces |

---

## Flex PCB (OM-FlexGrid-Flex)

The flexible sensor matrix wraps around the forearm to capture muscle pressure.

### Specifications
- **Sensor Grid:** 15 columns × 4 rows (60 total sensors)
- **Sensor Type:** Velostat pressure-sensitive pads
- **Output:** 21-pin header connecting to rigid PCB
- **Profile:** Thin, wearable design (~3mm depth with sensors)

### Files
```
OM-FlexGrid-Flex/
├── OM-FlexGrid-Flex.kicad_sch      # Schematic
├── OM-FlexGrid-Flex.kicad_pcb      # PCB layout
├── OM-FlexGrid-Flex.kicad_pro      # Project file
├── V2-1 Gerber/                    # Latest fabrication files
├── V2-1 Gerber.zip                 # Ready for manufacturing
├── FlexStiff.stl                   # 3D model for stiffener
└── *.svg                           # Outline drawings
```

---

## Rigid PCB (OM-FlexGrid-Rigid-PCB)

The main controller board handles sensor scanning, processing, display, and communication.

### MCU
- **ESP32-S3-WROOM-1-N16R8**
  - 16MB Flash / 8MB PSRAM
  - Native USB, Wi-Fi, BLE
  - 4 ADC inputs for row sensing
  - Boot/Reset via tactile switches

### Sensor Interface
- **CD74HC4067** 16-channel multiplexer
  - 15 columns active
  - Sequential scanning with 4 simultaneous row reads
  - 60 readings per scan frame

### Display & IMU
- **SSD1306** OLED 128×32 (I2C)
- **ICM-42688-P** 6-DOF IMU (I2C, optional)

### Power Management
| Component | Function |
|---|---|
| TPS7A0333 | 3.3V LDO regulator |
| LTC4054ES5 | Single-cell LiPo charger |
| MAX16054 | Smart pushbutton power latch |

### User Interface
- **Buttons:** MENU, SELECT, BOOT, RESET
- **Haptic:** MOSFET-driven vibration motor (IRLML2060)
- **USB-C:** Charging, programming, serial debug

### Files
```
OM-FlexGrid-Rigid-PCB/
├── OM-FlexGrid-Rigid-PCB.kicad_sch         # Schematic
├── OM-FlexGrid-Rigid-PCB.kicad_pcb         # PCB layout
├── OM-FlexGrid-Rigid-PCB.kicad_pro         # Project file
├── OM-FlexGrid-Rigid-PCB.step              # 3D model
├── OM-FlexGrid-Rigid-PCB-Gerber-V2-1/      # Latest fabrication files
├── OM-FlexGrid-Rigid-PCB-Gerber-V2-1.zip   # Ready for manufacturing
└── OmFlexGridArtV2.svg                     # Silkscreen artwork
```

---

## V2 Development Goals

### FFC/FPC Connection Improvement
The primary focus of V2 is strengthening the FFC/FPC connection between the flex and rigid PCBs. The V1 connection was not robust enough for reliable wearable use. V2 explores connector options and mechanical reinforcement to ensure the connection holds up during daily wear and movement.

### Fabric Enclosure & Harness Testing
V2 is being tested with a custom fabric enclosure that houses both PCBs. This tests:
- Mechanical stress on board-to-board connections
- Overall harness durability
- Ergonomics and comfort during extended wear
- Real-world wearability on different forearm sizes

## Changes from V1

- Improved trace routing and signal integrity
- Updated silkscreen artwork
- Refined board outlines
- Additional Gerber iterations (V2, V2-1)
- FFC/FPC connector exploration for improved reliability

---

## Manufacturing

Use the latest Gerber ZIP files for fabrication:
- **Flex:** `V2-1 Gerber.zip` or `Gerber_OM-FlexGrid-Flex_2025-11-14.zip`
- **Rigid:** `OM-FlexGrid-Rigid-PCB-Gerber-V2-1.zip`

Recommended: Order flex PCB with stiffener using `FlexStiff.stl` dimensions.

---

## Related Resources

- **Firmware:** https://github.com/Open-Muscle/OpenMuscle-Firmware
- **Documentation Hub:** https://github.com/Open-Muscle/OpenMuscle-Hub
- **Project Site:** https://openmuscle.org
- **Discord:** https://discord.gg/WstCaqUG63

---

## License

Hardware released under **CERN Open Hardware License v2.0**

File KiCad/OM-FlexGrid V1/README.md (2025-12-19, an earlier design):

# OM-FlexGrid V1 - Rigid PCB

Welcome to the repository for **OM-FlexGrid V1**, the first revision of the rigid portion of Open Muscle's flexible sensor interface. This KiCad project represents a crucial part of Open Muscle's modular architecture for wearable, open-source prosthetic sensor systems.

---

## 🔧 Overview
This board is a rigid PCB designed to interface with a flexible sensor grid. It includes:

- An **ESP32-S3-WROOM-1-N16R8** module with Wi-Fi/BLE support
- Support for **I2C devices**: SSD1306 OLED and ICM-42688-P IMU
- **Multiplexer (MUX)** interface for up to 60 sensor lines
- **Battery charging and power management** circuits
- **Pushbutton-based low-power on/off** control
- **USB-C interface** for charging, programming, and serial communication
- **User interface buttons** and **haptic feedback motor**

---

## 📦 Hardware Block Summary

### 🧠 MCU
- **ESP32-S3-WROOM-1-N16R8**
  - 16MB Flash / 8MB PSRAM
  - Native USB, Wi-Fi, BLE
  - ADC-connected to 4 ROW lines
  - Boot/Reset accessible via tactile switches

### 🖥️ Display
- **SSD1306 OLED (I2C)**
  - Connected to `SCL` / `SDA`
  - Provides user interface feedback

### 📐 IMU
- **ICM-42688-P** (I2C)
  - 6-DOF (gyro + accel)
  - For orientation and gesture sensing

### 🔢 Flex Sensor Array
- **CD74HC4067 16-channel Multiplexer**
  - Connected to 15 COL lines
  - SIG line connected to 4 ADC-row lines
  - Enables scanning a 15x4 grid of passive sensors (typically in the flex PCB)

### ⚡ Power Management
- **TPS7A0333 LDO** (3.3V output)
  - Powered by either USB or battery
  - Controlled via EN pin from the smart pushbutton
- **LTC4054ES5**
  - Single-cell LiPo charging from USB
  - Status LED pin for visual charge indicator
- **MAX16054**
  - Smart pushbutton controller with power latch circuit

### 🔘 Buttons
- `MENU`, `SELECT`, `BOOT`, `RESET`
- `BOOT` and `RESET` used for flashing and recovery

### 📳 Haptic Feedback
- MOSFET-driven vibration motor
- GPIO-controlled with flyback diode for safety

### 🔌 USB-C Interface
- Provides:
  - Power (VBUS)
  - USB Data
  - LiPo charging input
  - Debugging and firmware flashing

---

## 📁 File Structure
```
/KiCad/OM-FlexGrid V1/
├── OM-FlexGrid-Rigid-PCB.kicad_sch     # KiCad Schematic
├── OM-FlexGrid-Rigid-PCB.kicad_pcb     # PCB Layout
├── symbols/                            # Custom symbols (if any)
├── footprints/                         # Custom footprints (if any)
└── exports/                            # Exported fabrication files (optional)
```

---

## 💡 Usage Notes
- The rigid PCB is designed to pair with a **flexible sensor grid**.
- The MUX enables **high-density analog signal acquisition** using only 4 ADCs.
- Power control via MAX16054 allows **ultra-low-power standby**.
- OLED and IMU allow for rich feedback and motion awareness in prosthetic or wearable contexts.

---

## 📜 License
This hardware is released under the **CERN Open Hardware License v2.0**.

> Open Muscle is committed to making prosthetic technologies accessible to all. You are encouraged to fork, remix, and contribute to this project.

---

## 🧠 Learn More
- 🌐 https://openmuscle.org
- 🤝 Community: [Discord Invite Link](https://discord.gg/WstCaqUG63))
- 🛠️ Firmware Repo: https://github.com/Open-Muscle/OpenMuscle-Firmware

---

Let us know if you use this board or build on it—we'd love to feature your work!

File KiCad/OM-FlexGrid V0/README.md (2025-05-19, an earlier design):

# OpenMuscle FlexGrid (v2.0)

**OpenMuscle FlexGrid** is a modular wearable sensor grid with 60 analog pressure sensors arranged in a 15x4 matrix. It is the second-generation wearable in the OpenMuscle series and serves as the core interface for capturing muscle movement in prosthetic and robotics applications.

📍 Project Page: [openmuscle.org](https://openmuscle.org)

---

## 📐 System Overview

- **Sensor Grid**: 15 columns × 4 rows of Velostat pads
- **Flex PCB**: Thin and wearable with 21-pin output header
- **Rigid PCB**: ESP32-S3, haptic feedback, USB-C charging, multiplexer, OLED, IMU

---

## 🔧 Key Features

| Feature | Description |
|---|---|
| MCU | ESP32-S3 (USB + BLE + ADC1) |
| Sensor Matrix | 15×4 Velostat with voltage divider setup |
| Multiplexer | 74HC4067 (16-channel, 15 used) |
| Row Reads | 4x analog inputs on ADC1 |
| OLED Display | SSD1306 128x32 over I2C |
| IMU | ICM-42688-P 6-DOF sensor (optional) |
| Haptic Feedback | Motor driven by IRLML2060 MOSFET |
| Power Management | MAX16054 soft latch, TPS7A0333 LDO, LTC4054 LiPo charger |

---

## 🗂️ File Structure

```graphql
FlexGrid/
├── KiCad/ # Schematic and layout files
├── Images/ # Renders and photos
├── BOM.xlsx # Bill of materials (optional)
└── README.md # You're reading it!
```

# 📁 Repository Layout

```graphql
OpenMuscle-FlexGrid/
├── firmware/           # MicroPython or C code for scanning and I/O
├── hardware/
│   ├── KiCad/          # Schematics, PCB, BOMs
│   └── Images/         # Renders and assembly diagrams
├── docs/
│   └── Datasheets/     # ICs and reference materials
└── README.md
```
---

## 🛠️ How It Works

The 74HC4067 connects one column at a time to 3.3V. The Velostat pads act as pressure-sensitive resistors connected to row lines, which are pulled down with 10kΩ resistors and read via analog inputs.

A software loop cycles through all 15 columns, sampling all 4 rows each time for 60 total readings per frame.

---

## 🧪 Status

- ✅ Schematic Complete
- ✅ PCB Fabricated & Assembled
- 🛠️ Firmware In Progress
- 🧠 ML Integration Pipeline Active

---

## 🔗 Related Projects

- [SensorBracelet (OM-12)](../Version2/OM-Sensor-BandV2/)
- [Labeler (LASK5)](../../../Labeler/)

---

## 📝 License

- **Hardware**: CERN-OHL-P v2
- **Software/Firmware**: MIT

---

## 🤝 Get Involved

We welcome contributions, feedback, and forks. This project is part of a broader mission to open-source biomechanical sensing tools for all.

Visit **[openmuscle.org](https://openmuscle.org)** or join our Discord (link coming soon).

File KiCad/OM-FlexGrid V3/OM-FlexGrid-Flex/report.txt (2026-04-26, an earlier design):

Plotted to 'D:\MT2-TX\OneDrive - TURFPTAx\Documents\GitHub\OpenMuscle-FlexGrid\KiCad\OM-FlexGrid V3\V3 Flex PCB Gerber\OM-FlexGrid-Flex-F_Cu.gbr'.
Plotted to 'D:\MT2-TX\OneDrive - TURFPTAx\Documents\GitHub\OpenMuscle-FlexGrid\KiCad\OM-FlexGrid V3\V3 Flex PCB Gerber\OM-FlexGrid-Flex-B_Cu.gbr'.
Plotted to 'D:\MT2-TX\OneDrive - TURFPTAx\Documents\GitHub\OpenMuscle-FlexGrid\KiCad\OM-FlexGrid V3\V3 Flex PCB Gerber\OM-FlexGrid-Flex-F_Paste.gbr'.
Plotted to 'D:\MT2-TX\OneDrive - TURFPTAx\Documents\GitHub\OpenMuscle-FlexGrid\KiCad\OM-FlexGrid V3\V3 Flex PCB Gerber\OM-FlexGrid-Flex-B_Paste.gbr'.
Plotted to 'D:\MT2-TX\OneDrive - TURFPTAx\Documents\GitHub\OpenMuscle-FlexGrid\KiCad\OM-FlexGrid V3\V3 Flex PCB Gerber\OM-FlexGrid-Flex-F_Silkscreen.gbr'.
Plotted to 'D:\MT2-TX\OneDrive - TURFPTAx\Documents\GitHub\OpenMuscle-FlexGrid\KiCad\OM-FlexGrid V3\V3 Flex PCB Gerber\OM-FlexGrid-Flex-B_Silkscreen.gbr'.
Plotted to 'D:\MT2-TX\OneDrive - TURFPTAx\Documents\GitHub\OpenMuscle-FlexGrid\KiCad\OM-FlexGrid V3\V3 Flex PCB Gerber\OM-FlexGrid-Flex-F_Mask.gbr'.
Plotted to 'D:\MT2-TX\OneDrive - TURFPTAx\Documents\GitHub\OpenMuscle-FlexGrid\KiCad\OM-FlexGrid V3\V3 Flex PCB Gerber\OM-FlexGrid-Flex-B_Mask.gbr'.
Plotted to 'D:\MT2-TX\OneDrive - TURFPTAx\Documents\GitHub\OpenMuscle-FlexGrid\KiCad\OM-FlexGrid V3\V3 Flex PCB Gerber\OM-FlexGrid-Flex-Edge_Cuts.gbr'.
Plotted to 'D:\MT2-TX\OneDrive - TURFPTAx\Documents\GitHub\OpenMuscle-FlexGrid\KiCad\OM-FlexGrid V3\V3 Flex PCB Gerber\OM-FlexGrid-Flex-Stiffener.gbr'.
Created Gerber job file 'D:\MT2-TX\OneDrive - TURFPTAx\Documents\GitHub\OpenMuscle-FlexGrid\KiCad\OM-FlexGrid V3\V3 Flex PCB Gerber\OM-FlexGrid-Flex-job.gbrjob'.
Info: Done.
Info: Done.

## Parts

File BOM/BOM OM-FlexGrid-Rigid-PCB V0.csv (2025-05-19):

Reference | Value | Footprint | Datasheet | Qty | DNP | Exclude from BOM | Exclude from Board
BOOT1,MENU1,SELECT1,SW_PWR1,SW_RST1 | SW_Push | OpenMuscleDevKit:EVQP2P02M | ~ | 5
C5 | 100 nF | Capacitor_SMD:C_0402_1005Metric | ~ | 1
C6,C7 | 4.7uF | Capacitor_SMD:C_0805_2012Metric | ~ | 2
C8,C11 | 2.2 uF | Capacitor_SMD:C_0603_1608Metric | ~ | 2
C9 | 100 uF | Capacitor_SMD:C_0603_1608Metric | ~ | 1
C10 | 0.1 uF | Capacitor_SMD:C_0603_1608Metric | ~ | 1
D1 | 1N5819 | Diode_SMD:D_SOD-123F | http://www.vishay.com/docs/88525/1n5817.pdf | 1
D2 | CHRG LED | LED_SMD:LED_0805_2012Metric | ~ | 1
D3 | BAT54C | Package_TO_SOT_SMD:SOT-23 | http://www.diodes.com/_files/datasheets/ds11005.pdf | 1
D4 | 1N4007 | Diode_SMD:D_SOD-123 | http://www.vishay.com/docs/88503/1n4001.pdf | 1
GYRO1,SCRN1 | Conn_01x04 | Connector_PinHeader_2.54mm:PinHeader_1x04_P2.54mm_Vertical | ~ | 2
IC1 | ICM-42688-P | IIM42352 | https://3cfeqx1hf82y3xcoull08ihx-wpengine.netdna-ssl.com/wp-content/uploads/2021/06/DS-000347-ICM-42688-P-v1.5.pdf | 1
J1 | Conn_01x08_Pin | Connector_PinHeader_2.54mm:PinHeader_1x08_P2.54mm_Vertical | ~ | 1
J3 | Conn_01x21_Pin | Connector_PinSocket_2.54mm:PinSocket_1x21_P2.54mm_Vertical | ~ | 1
J4 | USB_C_Receptacle | Connector_USB:USB_C_Receptacle_HRO_TYPE-C-31-M-12 | https://www.usb.org/sites/default/files/documents/usb_type-c.zip | 1
J5 | Conn_01x02 | Connector_PinHeader_2.00mm:PinHeader_1x02_P2.00mm_Vertical | ~ | 1
MAX1 | MAX16054AZT+T | Package_TO_SOT_SMD:SOT-23-6 |  | 1
Q1,Q3 | IRLML2060 | Package_TO_SOT_SMD:SOT-23 | https://www.infineon.com/dgdl/irlml2060pbf.pdf?fileId=5546d462533600a401535664b7fb25ee | 2
Q2 | VP0610T | Package_TO_SOT_SMD:SOT-23 | http://www.vishay.com/docs/70209/70209.pdf | 1
R1,R2,R6 | 5.1K | Resistor_SMD:R_0603_1608Metric | ~ | 3
R3 | 1K | Resistor_SMD:R_0603_1608Metric | ~ | 1
R4 | 2k | Resistor_SMD:R_0603_1608Metric | ~ | 1
R5 | 150 | Resistor_SMD:R_0603_1608Metric | ~ | 1
R7,R8,R9 | 100k | Resistor_SMD:R_0603_1608Metric | ~ | 3
R10,R11,R12,R13,R14,R15,R16 | 10k | Resistor_SMD:R_0603_1608Metric | ~ | 7
U1 | CD74HC4067M | Package_SO:SOIC-24W_7.5x15.4mm_P1.27mm | http://www.ti.com/lit/ds/symlink/cd74hc4067.pdf | 1
U2 | ESP32-S3-WROOM-1-N16R8 | footprints:ESP32-S3-WROOM-1-N16R8 | ESP32-S3-WROOM-1-N16R8 | 1
U3 | TPS7A03 | Package_TO_SOT_SMD:SOT-23-5 | https://www.ti.com/lit/ds/symlink/tps7a05.pdf | 1
U4 | LTC4054ES5-4.2 | Package_TO_SOT_SMD:TSOT-23-5 | https://www.analog.com/media/en/technical-documentation/data-sheets/405442xf.pdf | 1

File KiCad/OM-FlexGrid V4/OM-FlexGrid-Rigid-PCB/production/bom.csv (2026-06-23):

Designator | Footprint | Quantity | Value | LCSC Part #
BOOT1, MENU1, SELECT1, SW_PWR1, SW_RST1 | EVQP2P02M | 5 | SW_Push | C512395
C10 | 0603 | 1 | 0.1 uF | C14663
C11, C8 | 0603 | 2 | 2.2 uF | C23630
C12, C13, C14, C15 | 0603 | 4 | 100 pF | C23630
C5 | 0603 | 1 | 100 nF | C14663
C6, C7 | 0805 | 2 | 4.7uF | C1779
C9 | 0603 | 1 | 100 uF | C100082
D1 | D_SOD-123 | 1 | 1N5819 | C64885
D2 | 0805 | 1 | CHRG LED | C2297
D3 | SOT-23 | 1 | BAT54C | C22466350
D4 | D_SOD-123 | 1 | 1N4007 | C22440662
D5 | LED_RGB_PLCC-6 | 1 | LED_RGB | C2827305
IC1 | LGA-14_3x2.5mm_P0.5mm_LayoutBorder3x4y | 1 | ICM-42688-P | C54308212
J1 | PinHeader_2x03_P1.27mm_Vertical | 1 | Conn_01x06_Pin
J2 | PinHeader_1x02_P2.54mm_Vertical | 1 | BAT Terminal
J3 | 687120183722-20P-Bottom | 1 | Conn_01x20
J4 | USB_C_Receptacle_HRO_TYPE-C-31-M-12 | 1 | USB_C_Receptacle
J5 | PinHeader_1x02_P2.00mm_Vertical | 1 | Conn_01x02
J6 | PinHeader_1x03_P2.54mm_Vertical | 1 | Conn_01x03_Pin
J7 | PinSocket_1x02_P2.00mm_Vertical | 1 | Conn_01x02_Pin
J9 | CONN_503398-1892_MOL | 1 | Micro_SD_Card
MAX1 | TSOT-23-6 | 1 | MAX16054 | C79401
Q1, Q3 | SOT-23 | 2 | IRLML2060 | C67275
Q2 | SOT-23 | 1 | VP0610T or BSS84 | C8492
R1, R2, R6 | 0603 | 3 | 5.1K | C23186
R10, R11, R12, R13, R14, R15 | 0603 | 6 | 10k | C25804
R16, R17, R18 | 0603 | 3 | 330 | C23138
R3 | 0603 | 1 | 1K | C21190
R4 | 0603 | 1 | 2k | C22975
R5 | 0603 | 1 | 150 | C22808
R7, R8, R9 | 0603 | 3 | 100k | C25803
SCRN1 | PinHeader_1x04_P2.54mm_Vertical | 1 | Conn_01x04
U1 | TSSOP-24_4.4x7.8mm_P0.65mm | 1 | CD74HC4067M
U2 | ESP32-S3-WROOM-1-N16R8 | 1 | ESP32-S3-WROOM-1-N16R8
U3 | SOT-23-5 | 1 | TPS7A03 | C2873330
U4 | TSOT-23-5 | 1 | LTC4054ES5-4.2 or STC4054GR | C262930
U5 | SOT-23-6 | 1 | USBLC6-2SC6 | C2687116

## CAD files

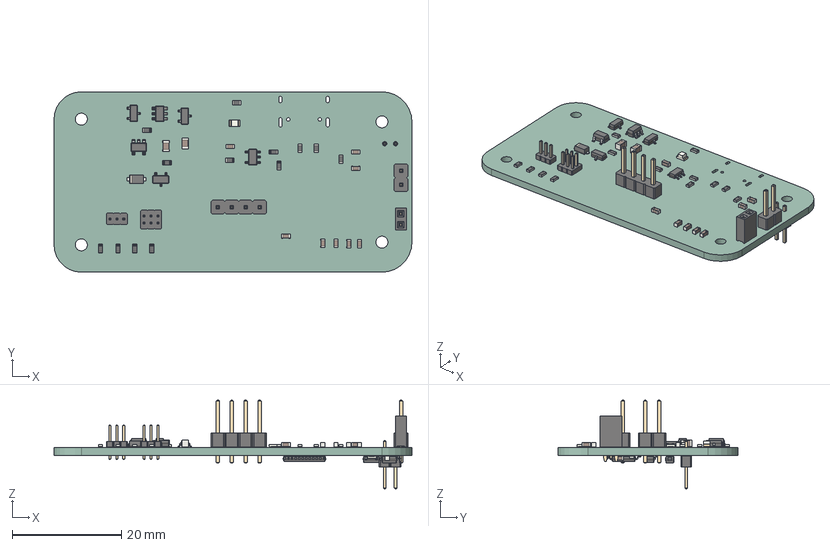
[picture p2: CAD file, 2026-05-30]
KiCad/OM-FlexGrid V4/OM-FlexGrid-Rigid-STEP.step
65.5 x 33.0 x 16.2 mm
R_0603_1608Metric x 15
D_SOD_123F
SOT-23-5
PinHeader_2x03_P127mm_Vertical
C_0603_1608Metric x 9
SOT-23 x 4
PinSocket_1x02_P2.00mm_Vertical
SOT-23-6
LED_0805_2012Metric
PinHeader_1x02_P254mm_Vertical
C_0805_2012Metric x 2
PinHeader_1x04_P254mm_Vertical
TSOT-23-5
PinHeader_1x03_P127mm_Vertical
TSSOP-24_4.4x7.8mm_P0.65mm
PinHeader_1x02_P200mm_Vertical
D_SOD-123
OM-FlexGrid-Rigid-PCB_PCB

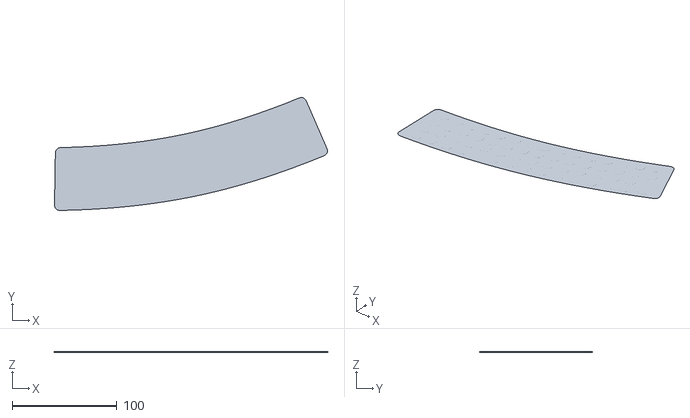
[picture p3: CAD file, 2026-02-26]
KiCad/OM-FlexGrid V4/FlexCurveGrid.stl
260.4 x 107.7 x 0.4

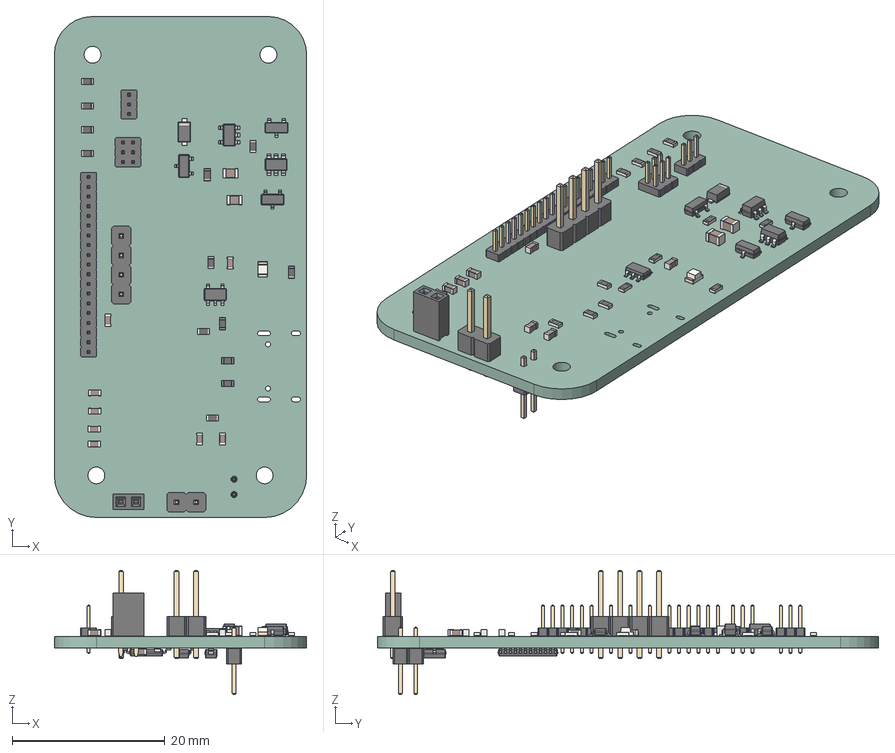
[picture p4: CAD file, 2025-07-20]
KiCad/OM-FlexGrid V4/OM-FlexGrid-Rigid-PCB/OM-FlexGrid-Rigid-PCB.step
33.0 x 65.5 x 16.2 mm
R_0603_1608Metric x 15
D_SOD-123F
SOT-23-5
PinHeader_2x03_P1.27mm_Vertical
C_0603_1608Metric x 9
SOT-23 x 4
PinSocket_1x02_P2.00mm_Vertical
SOT-23-6
LED_0805_2012Metric
PinHeader_1x02_P2.54mm_Vertical
C_0805_2012Metric x 2
PinHeader_1x04_P2.54mm_Vertical
TSOT-23-5
PinHeader_1x19_P1.27mm_Vertical
PinHeader_1x03_P1.27mm_Vertical
TSSOP-24_4.4x7.8mm_P0.65mm
PinHeader_1x02_P2.00mm_Vertical
D_SOD-123
OM-FlexGrid-Rigid-PCB_PCB

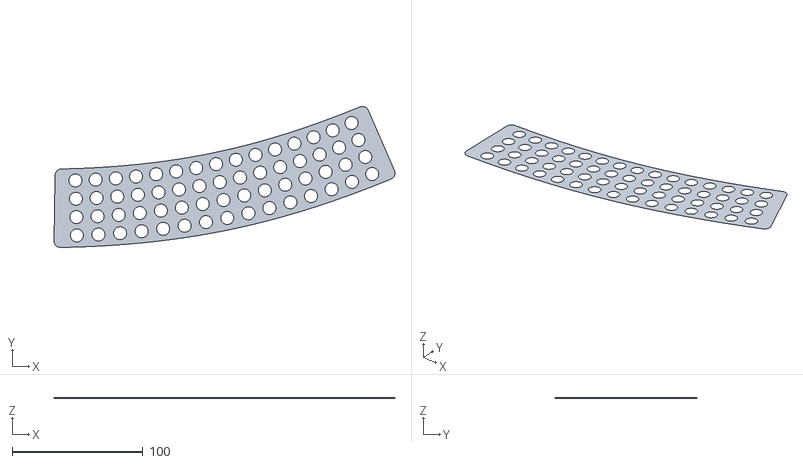
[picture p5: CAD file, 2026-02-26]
KiCad/OM-FlexGrid V4/FlexCurveGrid-cut.stl
260.4 x 107.7 x 0.3

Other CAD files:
KiCad/OM-FlexGrid V4/OM-FlexGrid-Flex/OM-FlexGrid-Rigid-STEP.step
KiCad/OM-FlexGrid V4/OM-FlexGrid-Rigid-PCB/3dmodels/Molex_503398-1892.step
KiCad/OM-FlexGrid V4/OM-FlexGrid-Rigid-PCB/OM-FlexGrid-Rigid-STEP.step
KiCad/OM-FlexGrid V4/OM-FlexGrid-Rigid-PCB/3dmodels/USB_C_HRO_TYPE-C-31-M-12.step
KiCad/OM-FlexGrid V4/OM-FlexGrid-Rigid-PCB/3dmodels/ESP32-S3-WROOM-1_aligned.STEP
KiCad/OM-FlexGrid V4/OM-FlexGrid-Rigid-PCB/3dmodels/Wurth_687120183722.step
KiCad/OM-FlexGrid V4/OM-FlexGrid-Rigid-PCB/3dmodels/EVQ-P2P02M.step
KiCad/OM-FlexGrid V4/OM-FlexGrid-Rigid-PCB/3dmodels/Molex_503398-1892_aligned.step
KiCad/OM-FlexGrid V4/OM-FlexGrid-Rigid-PCB/3dmodels/EVQ-P2P02M_aligned.step
KiCad/OM-FlexGrid V4/OM-FlexGrid-Rigid-PCB/3dmodels/ESP32-S3-WROOM-1.STEP
KiCad/OM-FlexGrid V4/OM-FlexGrid-Rigid-PCB/3dmodels/5033981892.stp
KiCad/OM-FlexGrid V4/OM-FlexGrid-Rigid-PCB/3dmodels/687120183722 (rev1).stp
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

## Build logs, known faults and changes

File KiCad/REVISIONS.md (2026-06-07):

# OM-FlexGrid Revision History

Quick cross-version comparison for anyone walking up to the repo cold. For per-revision detail, follow the link in each row to that revision's README.

| Revision | Status | Year | Headline change | Detail |
|---|---|---|---|---|
| **V4** | In design (paper) | 2026 | microSD + RGB status LED + slimmer reorientation | [`OM-FlexGrid V4/README.md`](OM-FlexGrid%20V4/README.md) |
| **V3** | Production-quality matrix (validated) | 2026 | Wurth FFC interconnect; matrix usable as ML training source | [`OM-FlexGrid V3/README.md`](OM-FlexGrid%20V3/README.md) |
| **V2** | Deprecated | 2025 | Pre-FFC, used hand-soldered pin headers between flex and rigid | [`OM-FlexGrid V2/README.md`](OM-FlexGrid%20V2/README.md) |
| **V1** | Archived | 2025 | Early prototype | [`OM-FlexGrid V1/`](OM-FlexGrid%20V1/) |
| **V0** | Archived | 2024 | Initial proof-of-concept | [`OM-FlexGrid V0/`](OM-FlexGrid%20V0/) |

---

## V4 (in design, 2026)

**Headline:** Wearable-ready upgrade. On-device data logging via microSD, glance-tells via RGB status LED, slimmer board geometry for a bracelet fit. Builds on the V3 production baseline; not yet fabbed.

**Key adds vs V3:**
- microSD card socket (Molex 5033981892, LCSC C428492) wired in SPI mode
- Discrete common-cathode 0603 RGB LED on GPIO 40/41/42 (zero quiescent, no setup fee)
- Board re-rotated so the long axis runs along the forearm, lower-profile against the skin
- Footprint cleanup: 1N5819 and 1N4007 standardized on SOD-123 (was SOD-123F), resistors forced to 0603

**Open items before fab:** final LDO part pick, IMU LCSC choice (POP must be green), V4 Flex tail width fix (11.1 to 10.5 mm per Wurth datasheet), full BOM tier review.

**Hand-soldered after JLC assembly:** microSD socket, Wurth FFC connector, battery JST, pin headers.

[Full V4 README](OM-FlexGrid%20V4/README.md)

---

## V3 (production-quality matrix, May 2026)

**Headline:** First revision with a usable sensor matrix. Validated end-to-end on two physical boards. UDP telemetry over Wi-Fi confirmed reaching the desktop visualizer; matrix declared **usable as a real ML training data source** for the first time in the project's history.

**Key wins:**
- 60-cell matrix delivers clean single-cell press detection across all 60 sensors
- Peak ~1100 ADC counts on direct press, 22% carryover to next column, decays to noise floor within 3 columns, idle baseline exactly 0
- 59 Hz scan rate
- Wurth 687120183722 FFC interconnect mates cleanly with the integrated stiffened flex tail

**Known issues that V4 addresses:**
- Mixed diode footprints (SOD-123F vs SOD-123) caused LCSC mismatch pain during ordering
- Some resistors mid-design ended up on 0402 from the JLCPCB plugin's "auto-select alike"; cleaner to standardize on 0603
- No on-device storage or status indicator
- Original layout not optimized for bracelet form factor

**Firmware that makes V3 work:** [Open-Muscle/FlexGridV3-Firmware](https://github.com/Open-Muscle/FlexGridV3-Firmware) v0.1.7.

[Full V3 README](OM-FlexGrid%20V3/README.md)

---

## Pattern across revisions

The repo treats each revision as a frozen sibling directory under `KiCad/`. New revisions:

1. Start as a clean copy of the previous one (fab outputs and backups stripped)
2. Get committed as a baseline before any V(N) work begins, so subsequent commits show up as clean diffs
3. Are documented per-revision in their own README, with the status line at the top
4. Land into this cross-revision table once committed

Older revisions stay accessible in their original form; we never rewrite their history. Field-deployed V3 boards continue to function and continue to be supported by their firmware.

For the operating workflow that turns a routed KiCad project into a JLCPCB order, see [`../docs/JLCPCB_WORKFLOW.md`](../docs/JLCPCB_WORKFLOW.md).

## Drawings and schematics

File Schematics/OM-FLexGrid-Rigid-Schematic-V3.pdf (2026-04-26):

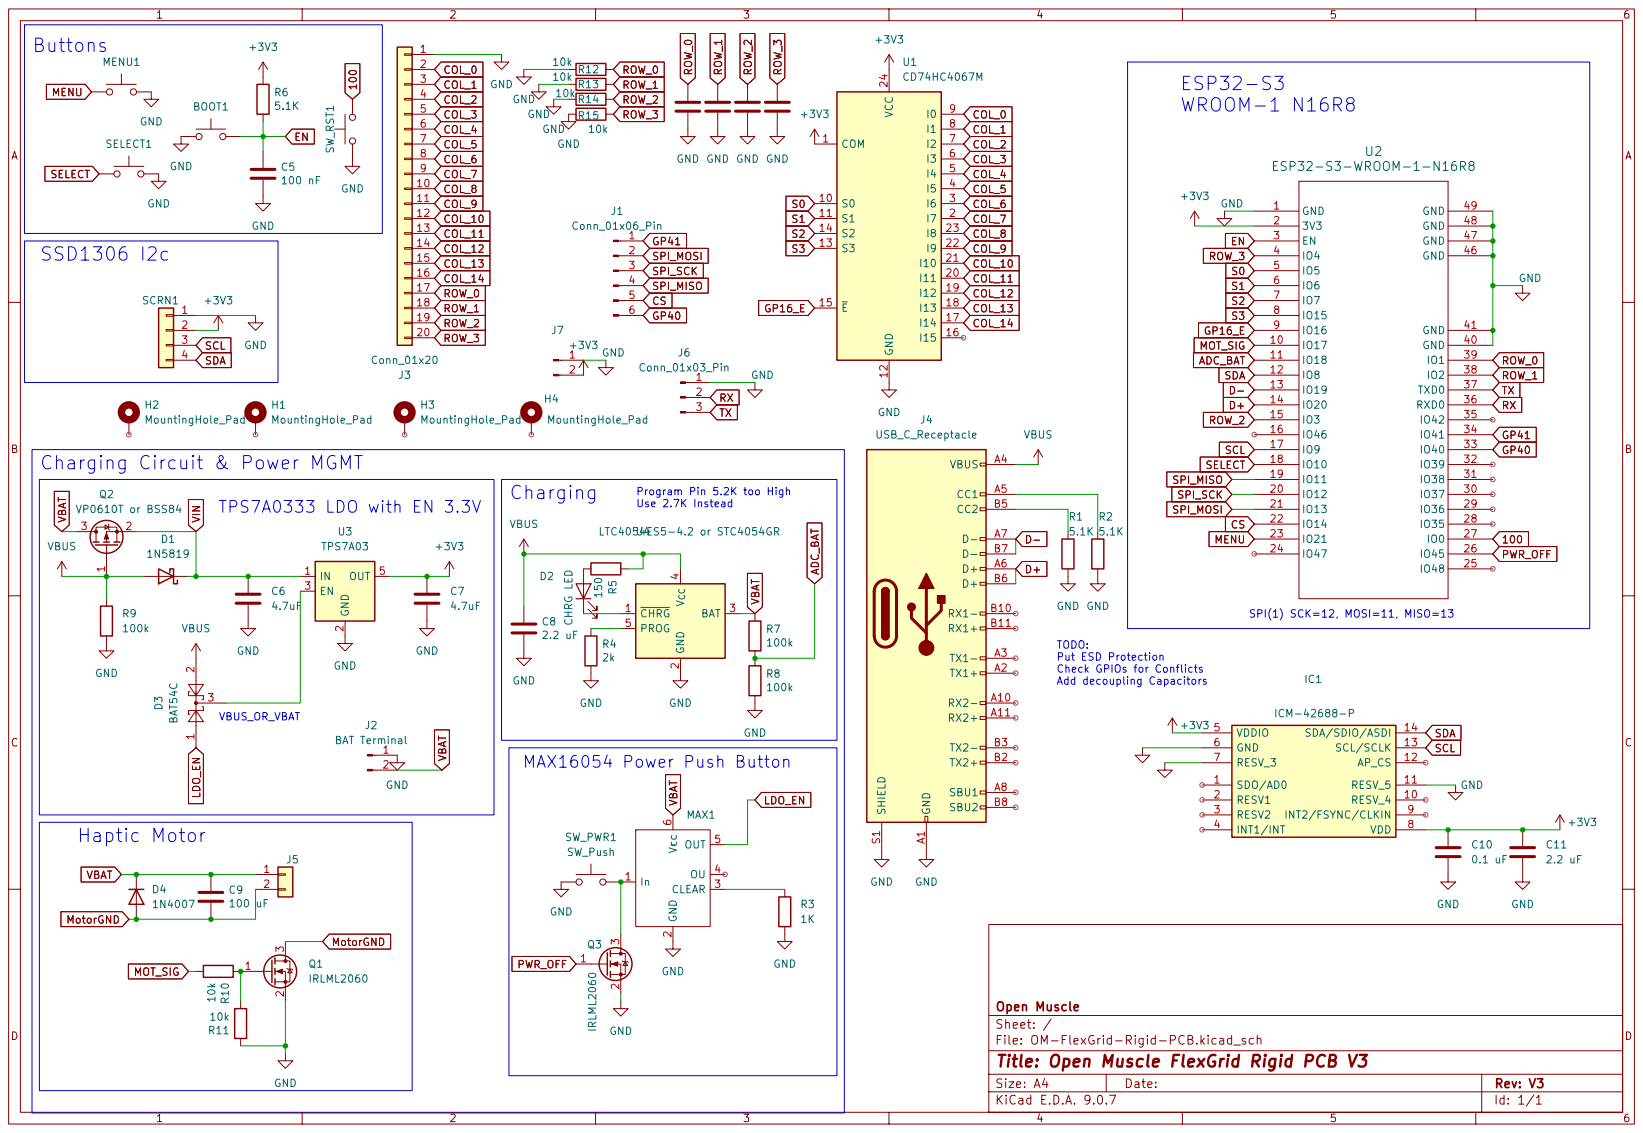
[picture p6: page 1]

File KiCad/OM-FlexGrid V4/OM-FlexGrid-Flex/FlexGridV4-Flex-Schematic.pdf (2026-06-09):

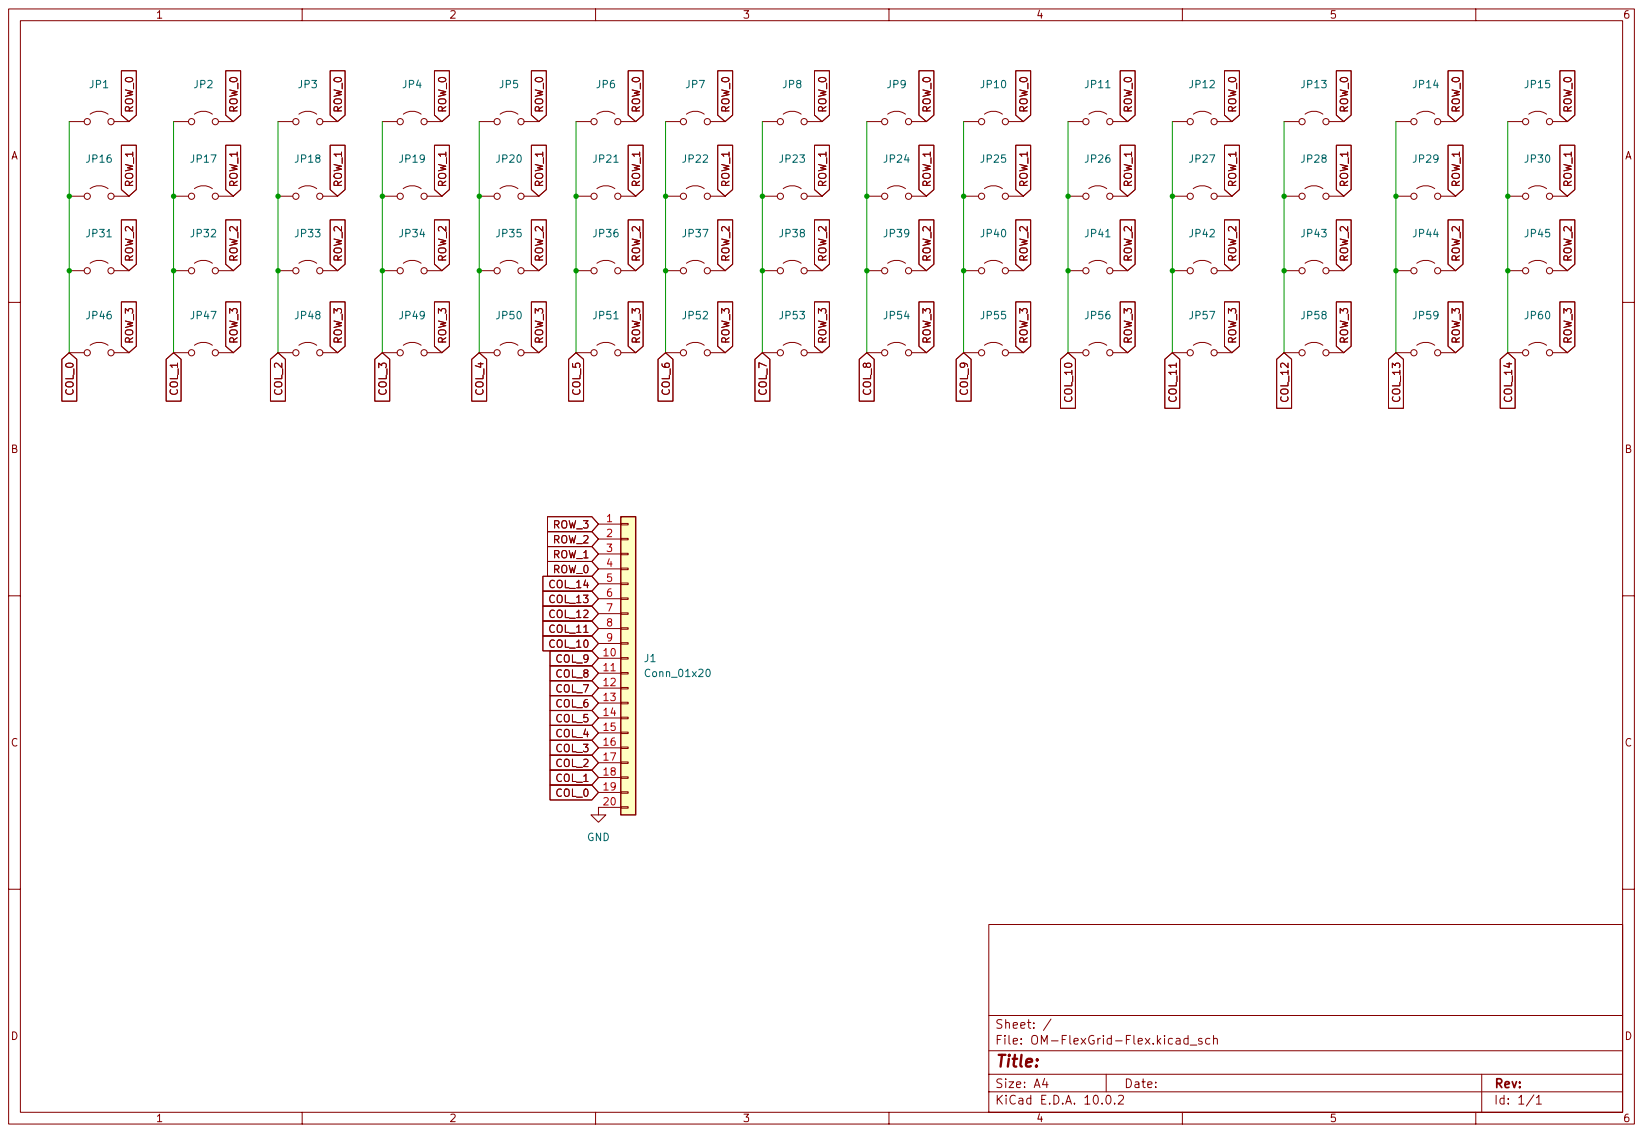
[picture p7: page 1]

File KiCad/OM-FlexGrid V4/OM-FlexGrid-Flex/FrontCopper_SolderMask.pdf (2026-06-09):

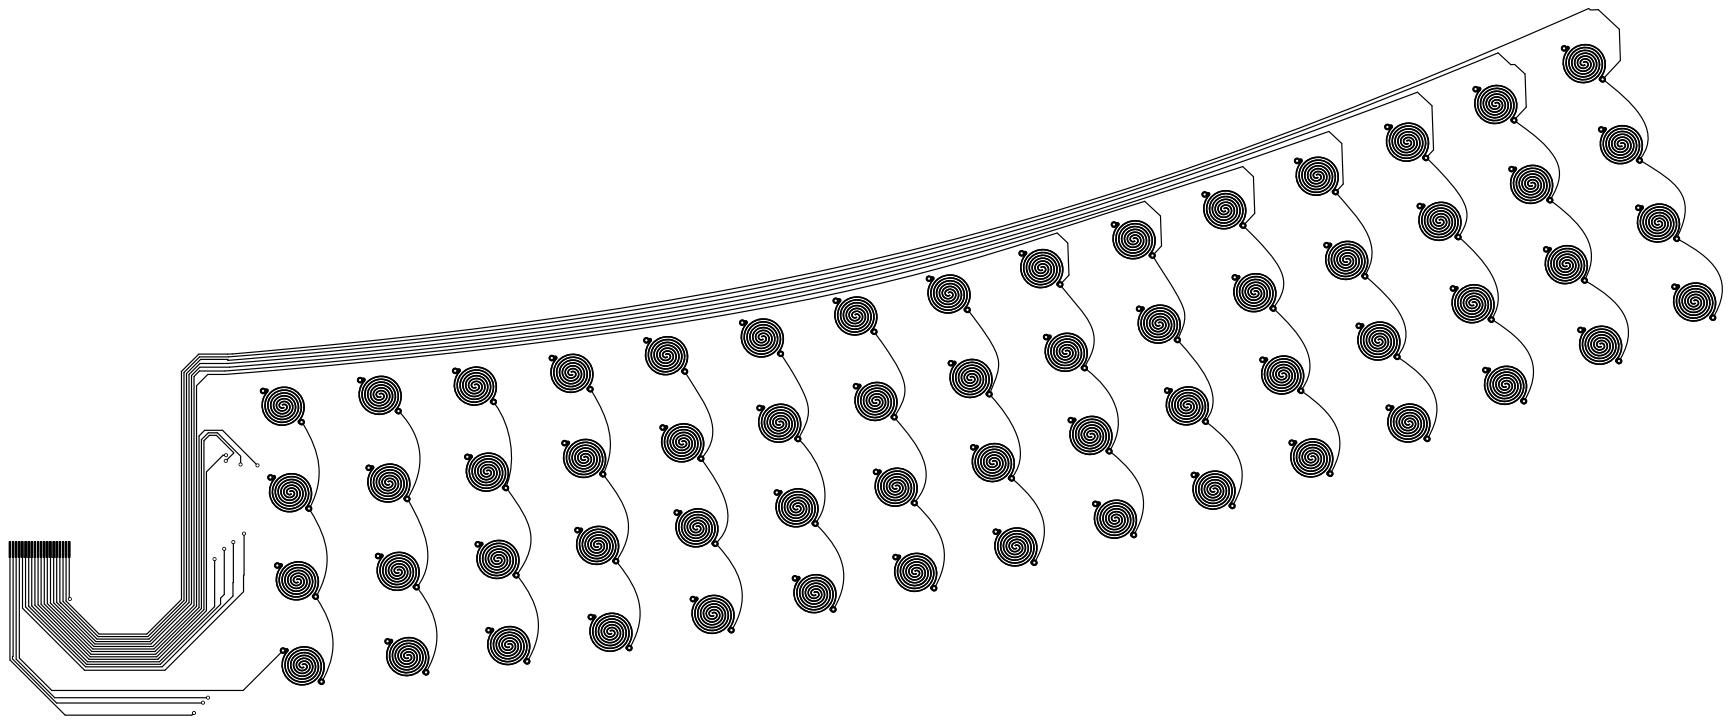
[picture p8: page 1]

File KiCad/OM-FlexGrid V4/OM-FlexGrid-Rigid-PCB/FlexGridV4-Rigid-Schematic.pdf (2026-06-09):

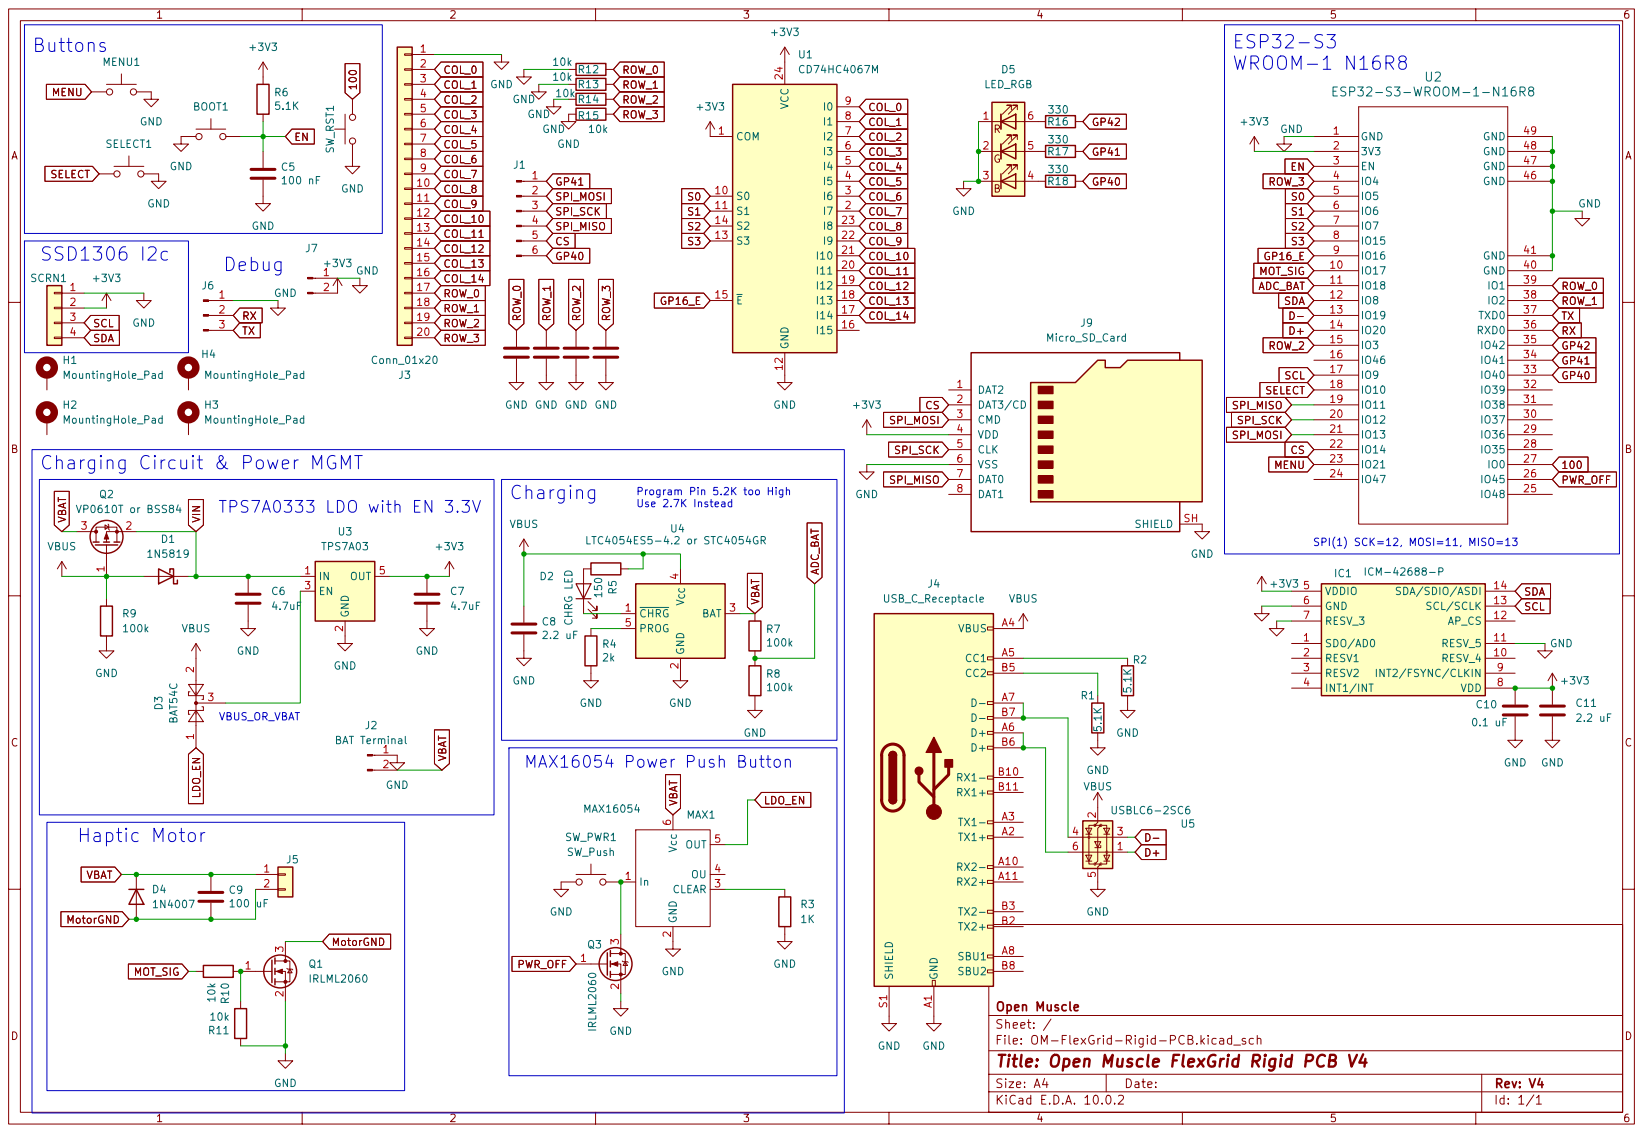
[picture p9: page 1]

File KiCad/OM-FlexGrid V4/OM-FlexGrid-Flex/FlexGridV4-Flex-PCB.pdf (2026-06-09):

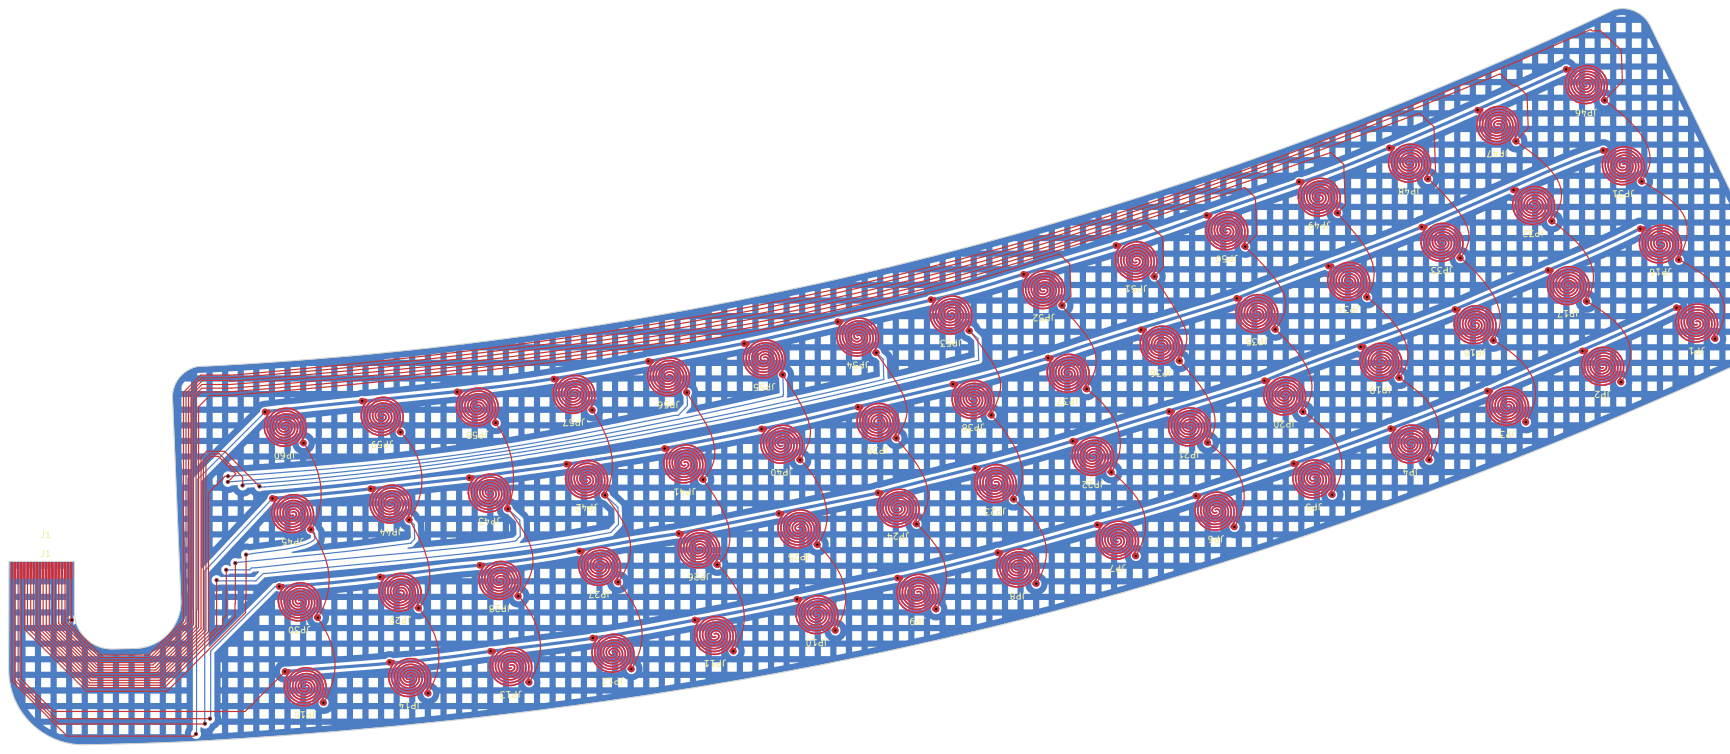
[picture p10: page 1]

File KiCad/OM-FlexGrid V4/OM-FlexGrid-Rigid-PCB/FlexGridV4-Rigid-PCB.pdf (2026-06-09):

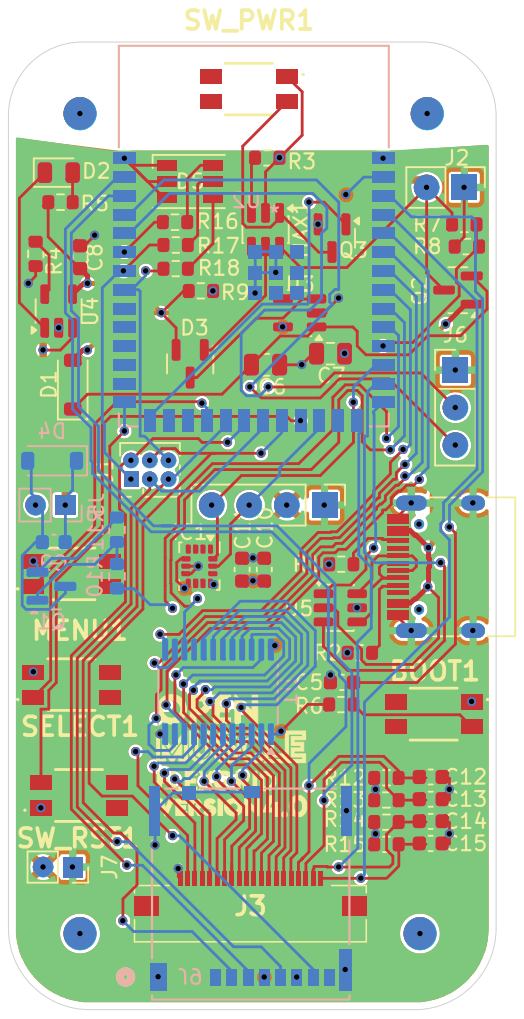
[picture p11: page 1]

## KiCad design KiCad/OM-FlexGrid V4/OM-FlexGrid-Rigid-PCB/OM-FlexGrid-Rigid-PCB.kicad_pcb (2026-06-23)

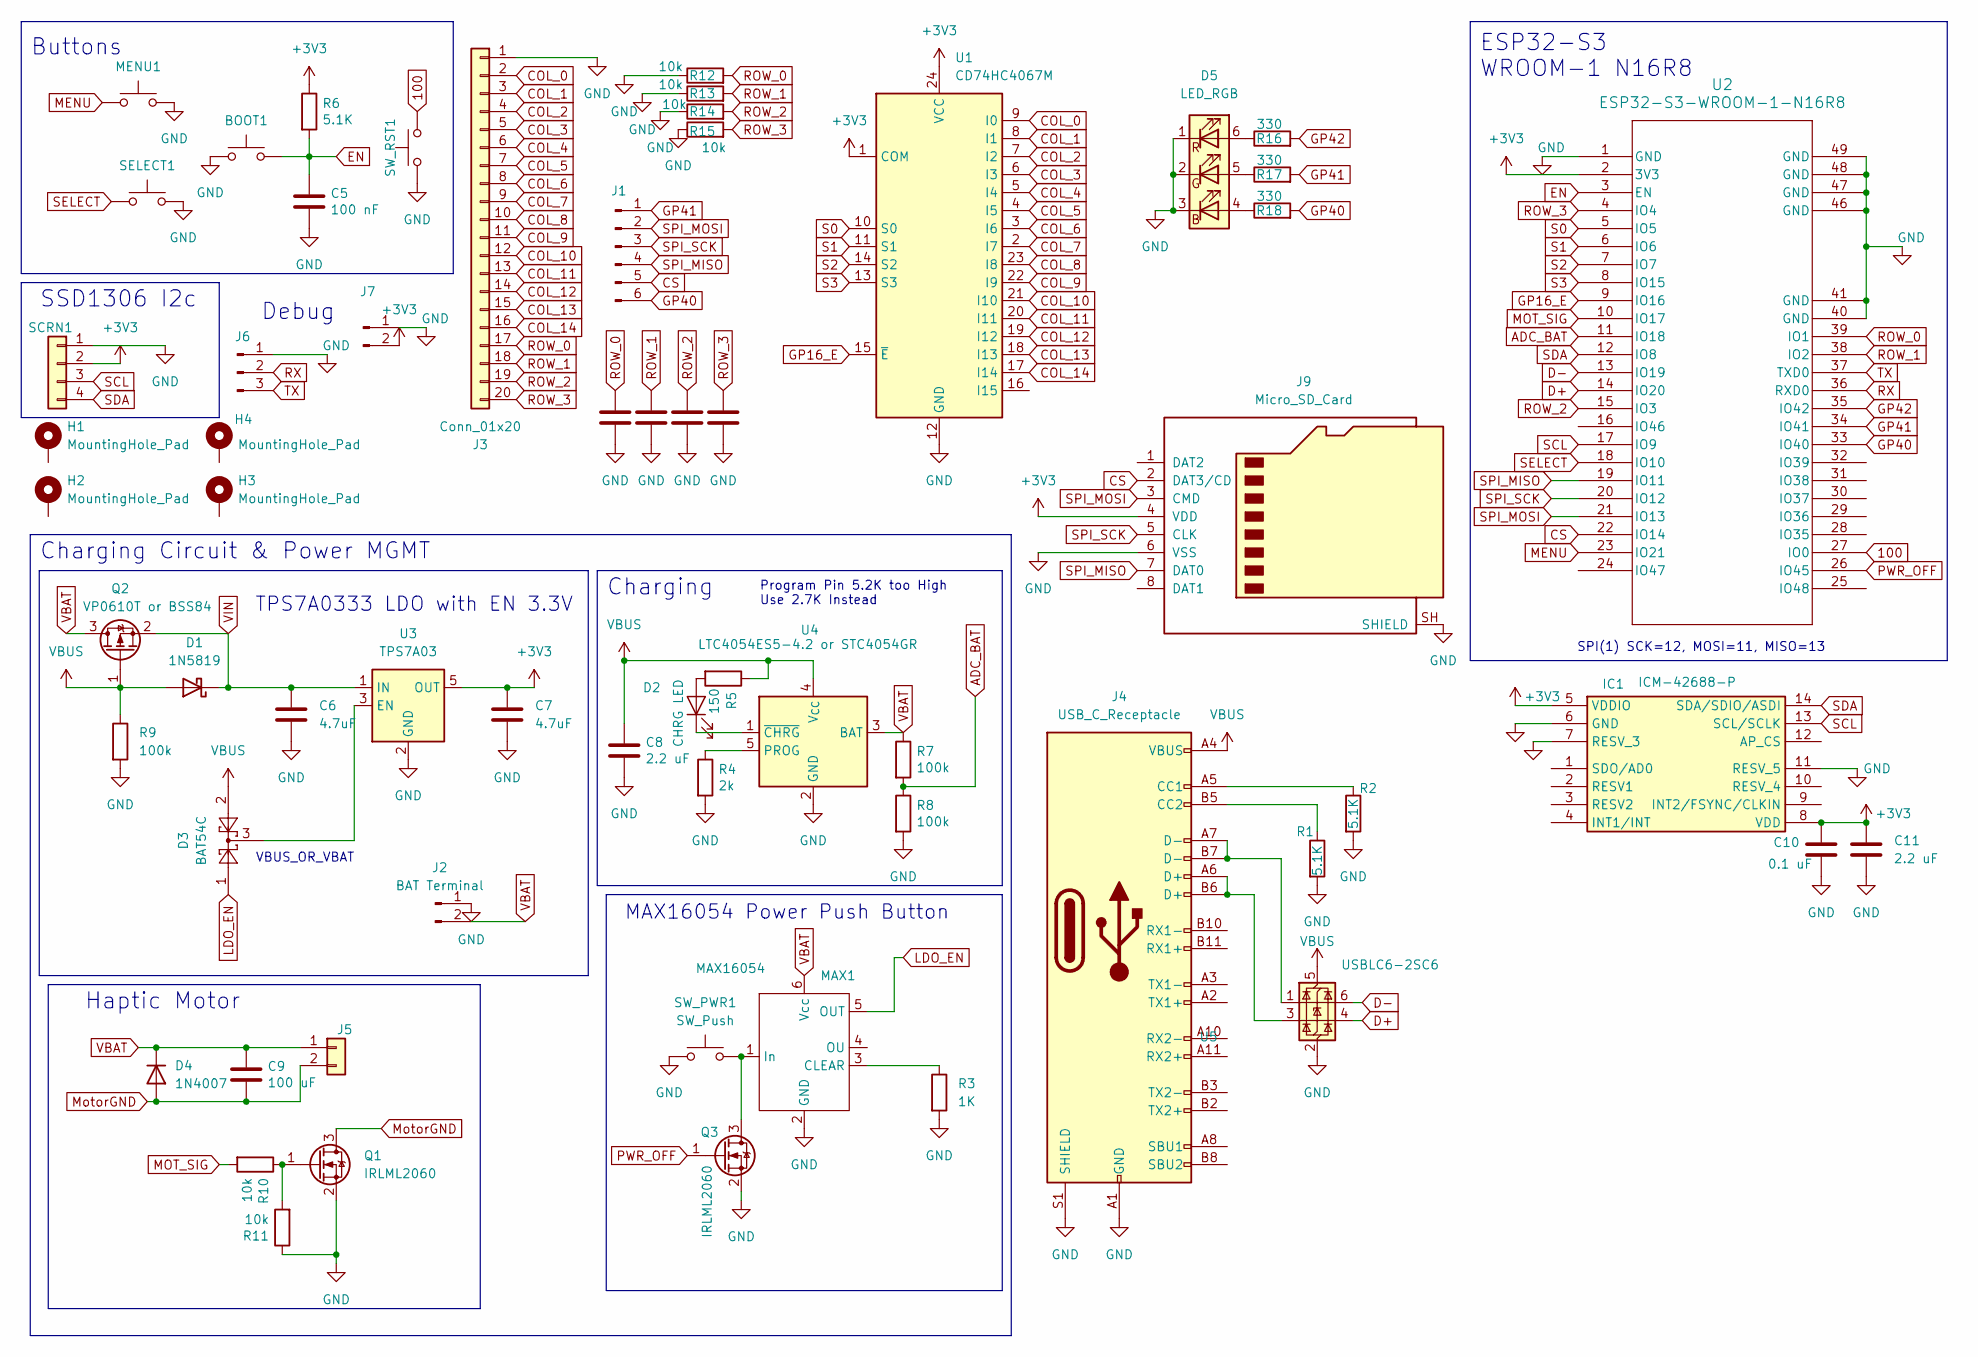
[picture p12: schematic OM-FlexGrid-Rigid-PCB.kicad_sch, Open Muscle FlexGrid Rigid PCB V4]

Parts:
BOOT1: SW_Push; EVQP2P02M; LCSC C512395
C5: 100 nF; C_0603_1608Metric; JLCPN C1525
C6, C7: 4.7uF; C_0805_2012Metric; LCSC C1779
C8: 2.2 uF; C_0603_1608Metric; JLCPN C12530
C9: 100 uF; C_0603_1608Metric; JLCPN C12530
C10: 0.1 uF; C_0603_1608Metric; LCSC C14663
C11: 2.2 uF; C_0603_1608Metric; LCSC C23630
C12, C13, C14, C15: 100 pF; C_0603_1608Metric; JLCPN C12530
D1: 1N5819; D_SOD-123; LCSC C64885
D2: CHRG LED; LED_0805_2012Metric; JLCPN C72043
D3: BAT54C; SOT-23; LCSC C22466350
D4: 1N4007; D_SOD-123; LCSC C22440662
D5: LED_RGB; LED_RGB_PLCC-6; LCSC C2827305
H1, H2, H3, H4: MountingHole_Pad; MountingHole_2.2mm_M2
IC1: ICM-42688-P; LGA-14_3x2.5mm_P0.5mm_LayoutBorder3x4y; Mouser Part Number 410-ICM-42688-P
J1: Conn_01x06_Pin; PinHeader_2x03_P1.27mm_Vertical
J2: BAT Terminal; PinHeader_1x02_P2.54mm_Vertical
J3: Conn_01x20; 687120183722-20P-Bottom
J4: USB_C_Receptacle; USB_C_Receptacle_HRO_TYPE-C-31-M-12
J5: Conn_01x02; PinHeader_1x02_P2.00mm_Vertical
J6: Conn_01x03_Pin; PinHeader_1x03_P2.54mm_Vertical
J7: Conn_01x02_Pin; PinSocket_1x02_P2.00mm_Vertical
J9: Micro_SD_Card; CONN_503398-1892_MOL
MAX1: MAX16054; TSOT-23-6; LCSC C79401
MENU1: SW_Push; EVQP2P02M; LCSC C512395
Q1, Q3: IRLML2060; SOT-23; LCSC C67275
Q2: VP0610T or BSS84; SOT-23; LCSC C8492
R1, R2, R6: 5.1K; R_0603_1608Metric; JLCPN C25905
R3: 1K; R_0603_1608Metric; LCSC C21190
R4: 2k; R_0603_1608Metric; JLCPN C25905
R5: 150; R_0603_1608Metric; JLCPN C4109
R7, R8: 100k; R_0603_1608Metric; JLCPN C25905
R9: 100k; R_0603_1608Metric; LCSC C25803
R10, R11: 10k; R_0603_1608Metric; JLCPN C25744
R12, R13, R14, R15: 10k; R_0603_1608Metric; JLCPN C25905
R16, R17, R18: 330; R_0603_1608Metric; JLCPN C25905
SCRN1: Conn_01x04; PinHeader_1x04_P2.54mm_Vertical
SELECT1: SW_Push; EVQP2P02M; LCSC C512395
SW_PWR1: SW_Push; EVQP2P02M; LCSC C512395
SW_RST1: SW_Push; EVQP2P02M; LCSC C512395
U1: CD74HC4067M; TSSOP-24_4.4x7.8mm_P0.65mm
U2: ESP32-S3-WROOM-1-N16R8
U3: TPS7A03; SOT-23-5; LCSC C2873330
U4: LTC4054ES5-4.2 or STC4054GR; TSOT-23-5; LCSC C262930
U5: USBLC6-2SC6; SOT-23-6; LCSC C2687116

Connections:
100: SW_RST1.2, U2.27 (IO0)
+3V3: C7.1, C10.1, C11.1, IC1.5 (VDDIO), IC1.8 (VDD), J7.2, J9.4 (VDD), R6.1, SCRN1.2, U1.1 (COM), U1.24 (VCC), U2.2 (3V3), U3.5 (OUT)
ADC_BAT: R7.2, R8.1, U2.11 (IO18)
COL_0: J3.2, U1.9 (I0)
COL_1: J3.3, U1.8 (I1)
COL_2: J3.4, U1.7 (I2)
COL_3: J3.5, U1.6 (I3)
COL_4: J3.6, U1.5 (I4)
COL_5: J3.7, U1.4 (I5)
COL_6: J3.8, U1.3 (I6)
COL_7: J3.9, U1.2 (I7)
COL_8: J3.10, U1.23 (I8)
COL_9: J3.11, U1.22 (I9)
COL_10: J3.12, U1.21 (I10)
COL_11: J3.13, U1.20 (I11)
COL_12: J3.14, U1.19 (I12)
COL_13: J3.15, U1.18 (I13)
COL_14: J3.16, U1.17 (I14)
CS: J1.5, J9.2 (DAT3/CD), U2.22 (IO14)
D+: U2.14 (IO20), U5.4 (I/O2)
D-: U2.13 (IO19), U5.6 (I/O1)
EN: BOOT1.2, C5.2, R6.2, U2.3 (EN)
GND: BOOT1.1, C5.1, C6.2, C7.2, C8.1, C10.2, C11.2, C12.1, C13.1, C14.1, C15.1, D5.1 (RK), D5.2 (GK), D5.3 (BK), IC1.6 (GND), IC1.7 (RESV_3), IC1.11 (RESV_5), J2.1, J3.1, J4.A1 (GND), J4.A12 (GND), J4.B1 (GND), J4.B12 (GND), J4.S1 (SHIELD), J6.1, J7.1, J9.6 (VSS), J9.SH (SHIELD), MAX1.2 (GND), MENU1.2, Q1.2 (S), Q3.2 (S), R1.2, R2.2, R3.2, R4.2, R8.2, R9.2, R11.1, R12.1, R13.1, R14.1, R15.1, SCRN1.1, SELECT1.2, SW_PWR1.1, SW_RST1.1, U1.12 (GND), U2.1 (GND), U2.40 (GND), U2.41 (GND), U2.46 (GND), U2.47 (GND), U2.48 (GND), U2.49 (GND), U3.2 (GND), U4.2 (GND), U5.2 (GND)
GP16_E: U1.15 (~E), U2.9 (IO16)
GP40: J1.6, R18.2, U2.33 (IO40)
GP41: J1.1, R17.2, U2.34 (IO41)
GP42: R16.2, U2.35 (IO42)
LDO_EN: D3.1, MAX1.5 (OUT)
MENU: MENU1.1, U2.23 (IO21)
MOT_SIG: R10.2, U2.10 (IO17)
MotorGND: C9.1, D4.2 (A), J5.2, Q1.3 (D)
unnamed: D2.2 (A), R5.2
unnamed: D2.1 (K), U4.1 (~CHRG)
unnamed: D5.4 (BA), R18.1
unnamed: D5.5 (GA), R17.1
unnamed: D5.6 (RA), R16.1
unnamed: J4.A5 (CC1), R2.1
unnamed: J4.B5 (CC2), R1.1
unnamed: J4.A6 (D+), J4.B6 (D+), U5.3 (I/O2)
unnamed: J4.A7 (D-), J4.B7 (D-), U5.1 (I/O1)
unnamed: MAX1.3 (CLEAR), R3.1
unnamed: MAX1.1 (In), Q3.3 (D), SW_PWR1.2
unnamed: Q1.1 (G), R10.1, R11.2
unnamed: D3.3, U3.3 (EN)
unnamed: R4.1, U4.5 (PROG)
PWR_OFF: Q3.1 (G), U2.26 (IO45)
ROW_0: C12.2, J3.17, R12.2, U2.39 (IO1)
ROW_1: C13.2, J3.18, R13.2, U2.38 (IO2)
ROW_2: C14.2, J3.19, R14.2, U2.15 (IO3)
ROW_3: C15.2, J3.20, R15.2, U2.4 (IO4)
RX: J6.2, U2.36 (RXD0)
S0: U1.10 (S0), U2.5 (IO5)
S1: U1.11 (S1), U2.6 (IO6)
S2: U1.14 (S2), U2.7 (IO7)
S3: U1.13 (S3), U2.8 (IO15)
SCL: IC1.13 (SCL/SCLK), SCRN1.3, U2.17 (IO9)
SDA: IC1.14 (SDA/SDIO/ASDI), SCRN1.4, U2.12 (IO8)
SELECT: SELECT1.1, U2.18 (IO10)
SPI_MISO: J1.4, J9.7 (DAT0), U2.19 (IO11)
SPI_MOSI: J1.2, J9.3 (CMD), U2.21 (IO13)
SPI_SCK: J1.3, J9.5 (CLK), U2.20 (IO12)
TX: J6.3, U2.37 (TXD0)
VBAT: C9.2, D4.1 (K), J2.2, J5.1, MAX1.6 (Vcc), Q2.3 (D), R7.1, U4.3 (BAT)
VBUS: C8.2, D1.2 (A), D3.2, J4.A4 (VBUS), J4.A9 (VBUS), J4.B4 (VBUS), J4.B9 (VBUS), Q2.1 (G), R5.1, R9.1, U4.4 (V_{CC}), U5.5 (VBUS)
VIN: C6.1, D1.1 (K), Q2.2 (S), U3.1 (IN)

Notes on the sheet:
Charging Circuit & Power MGMT
Haptic Motor
Buttons
ESP32-S3 WROOM-1 N16R8
TPS7A0333 LDO with EN 3.3V
SPI(1) SCK=12, MOSI=11, MISO=13
SSD1306 I2c
Program Pin 5.2K too High Use 2.7K Instead
MAX16054 Power Push Button
VBUS_OR_VBAT
Charging
Debug

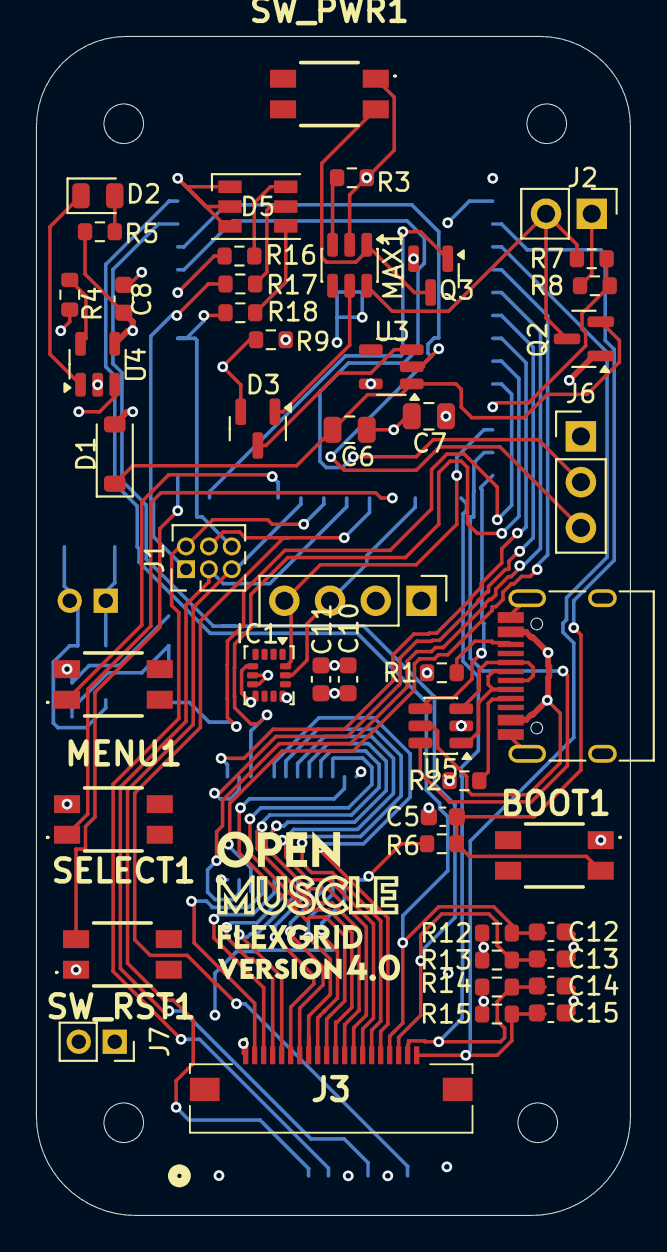
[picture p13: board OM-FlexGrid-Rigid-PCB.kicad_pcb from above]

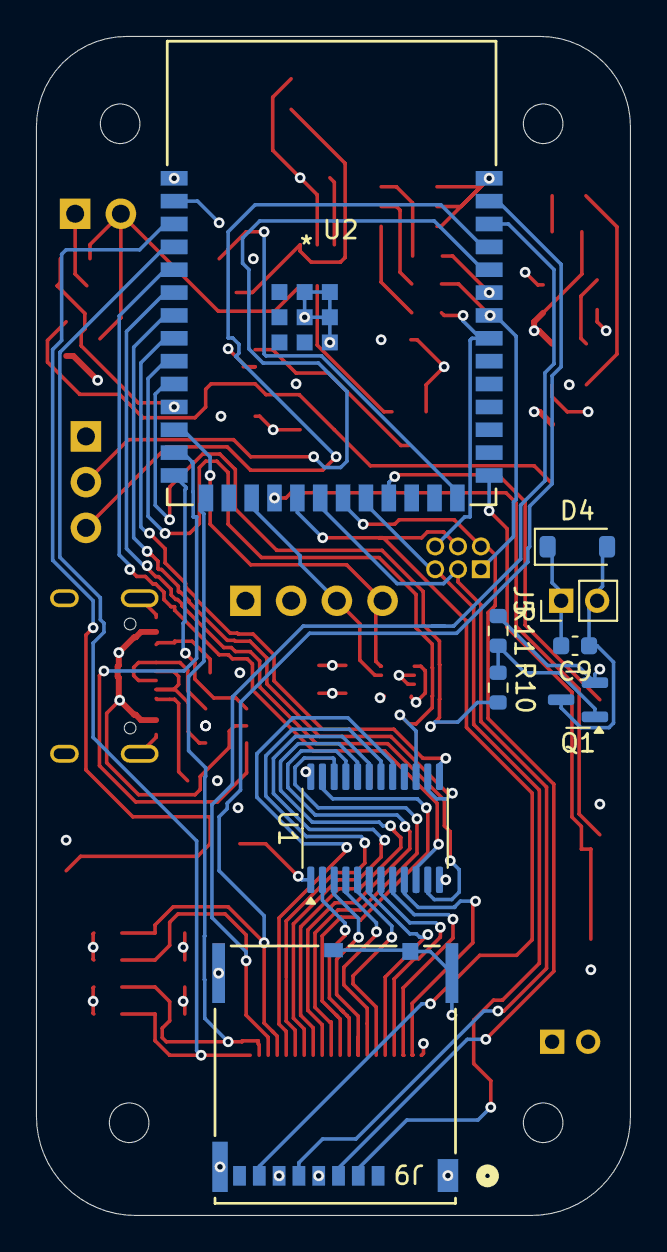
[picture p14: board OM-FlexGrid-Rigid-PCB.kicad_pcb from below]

Board: 4 copper layers, 33.0 x 65.5 mm, 62 parts (9 on the bottom side), 65 nets.

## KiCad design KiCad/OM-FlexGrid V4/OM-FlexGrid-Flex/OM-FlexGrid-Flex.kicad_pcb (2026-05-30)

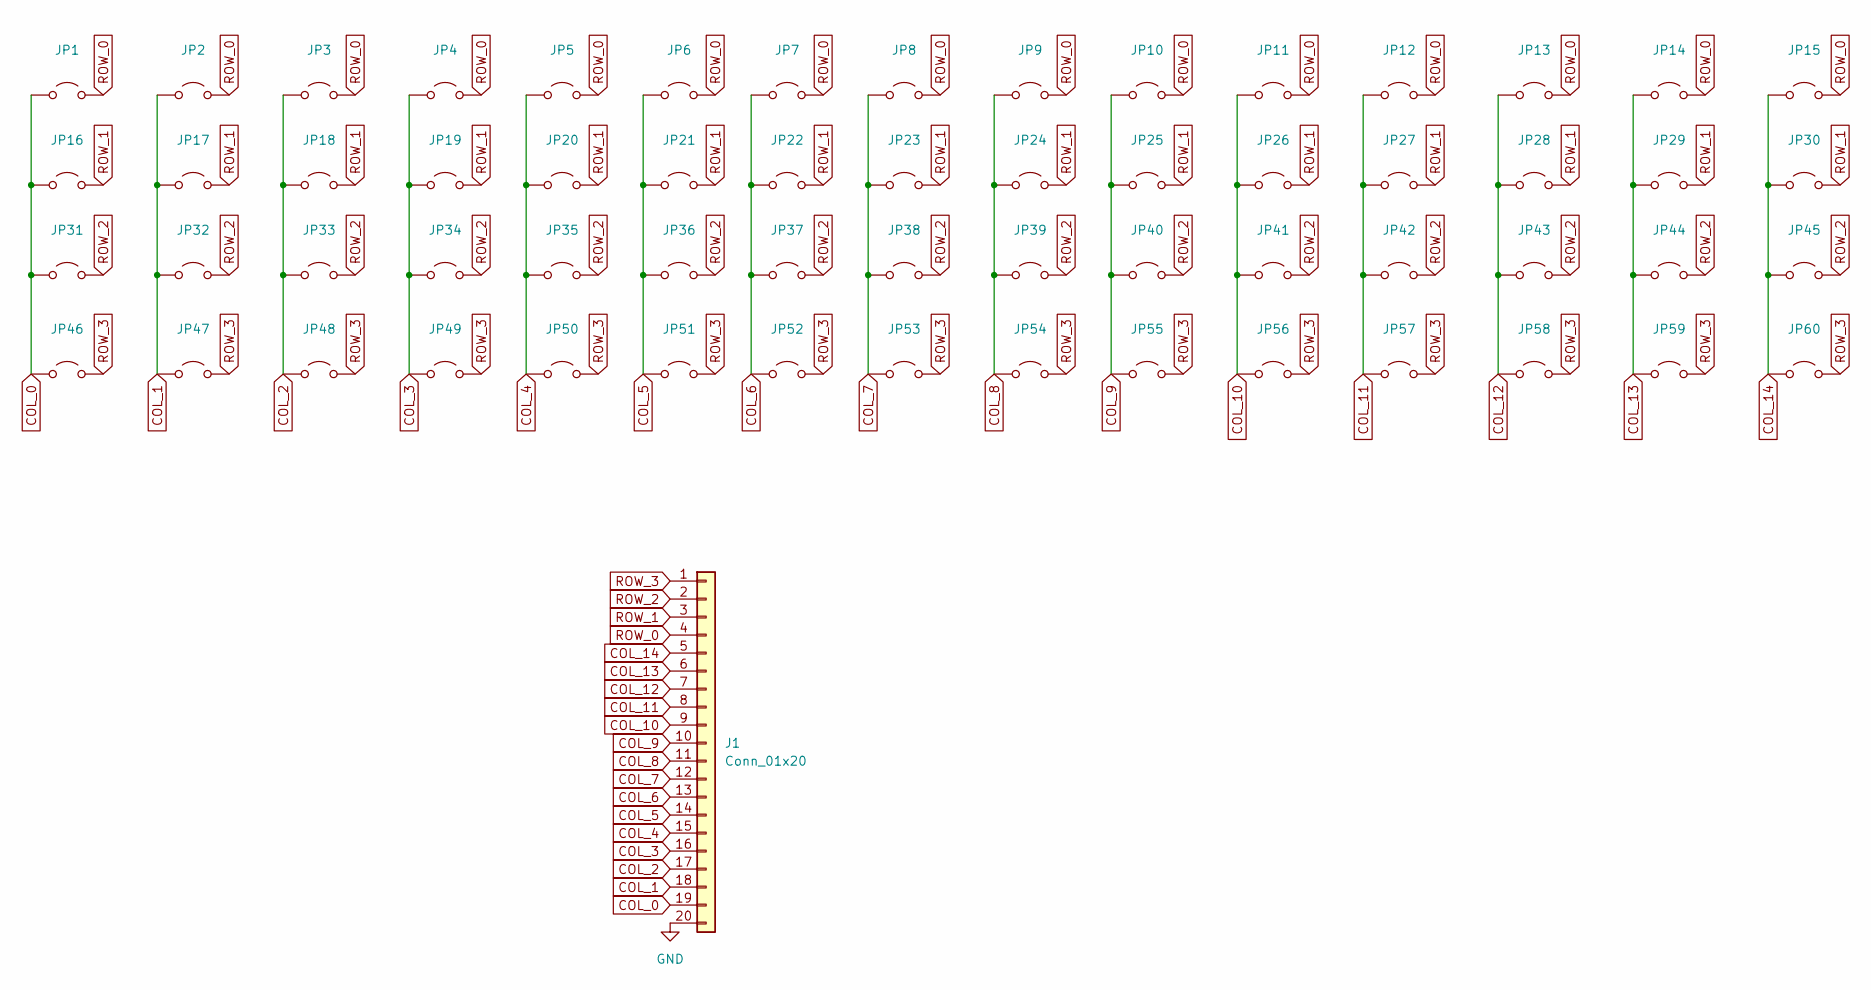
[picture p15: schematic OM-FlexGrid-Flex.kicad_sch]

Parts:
J1: Conn_01x20; 20Pin-FFC
JP1, JP2, JP3, JP4, JP5, JP6, JP7, JP8, JP9, JP10, JP11, JP12, JP13, JP14, JP15, JP16, JP17, JP18, JP19, JP20, JP21, JP22, JP23, JP24, JP25, JP26, JP27, JP28, JP29, JP30, JP31, JP32, JP33, JP34, JP35, JP36, JP37, JP38, JP39, JP40, JP41, JP42, JP43, JP44, JP45, JP46, JP47, JP48, JP49, JP50, JP51, JP52, JP53, JP54, JP55, JP56, JP57, JP58, JP59, JP60: Jumper_2_Open; 10mmPad

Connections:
COL_0: J1.19, JP1.1 (A), JP16.1 (A), JP31.1 (A), JP46.1 (A)
COL_1: J1.18, JP2.1 (A), JP17.1 (A), JP32.1 (A), JP47.1 (A)
COL_2: J1.17, JP3.1 (A), JP18.1 (A), JP33.1 (A), JP48.1 (A)
COL_3: J1.16, JP4.1 (A), JP19.1 (A), JP34.1 (A), JP49.1 (A)
COL_4: J1.15, JP5.1 (A), JP20.1 (A), JP35.1 (A), JP50.1 (A)
COL_5: J1.14, JP6.1 (A), JP21.1 (A), JP36.1 (A), JP51.1 (A)
COL_6: J1.13, JP7.1 (A), JP22.1 (A), JP37.1 (A), JP52.1 (A)
COL_7: J1.12, JP8.1 (A), JP23.1 (A), JP38.1 (A), JP53.1 (A)
COL_8: J1.11, JP9.1 (A), JP24.1 (A), JP39.1 (A), JP54.1 (A)
COL_9: J1.10, JP10.1 (A), JP25.1 (A), JP40.1 (A), JP55.1 (A)
COL_10: J1.9, JP11.1 (A), JP26.1 (A), JP41.1 (A), JP56.1 (A)
COL_11: J1.8, JP12.1 (A), JP27.1 (A), JP42.1 (A), JP57.1 (A)
COL_12: J1.7, JP13.1 (A), JP28.1 (A), JP43.1 (A), JP58.1 (A)
COL_13: J1.6, JP14.1 (A), JP29.1 (A), JP44.1 (A), JP59.1 (A)
COL_14: J1.5, JP15.1 (A), JP30.1 (A), JP45.1 (A), JP60.1 (A)
GND: J1.20
ROW_0: J1.4, JP1.2 (B), JP2.2 (B), JP3.2 (B), JP4.2 (B), JP5.2 (B), JP6.2 (B), JP7.2 (B), JP8.2 (B), JP9.2 (B), JP10.2 (B), JP11.2 (B), JP12.2 (B), JP13.2 (B), JP14.2 (B), JP15.2 (B)
ROW_1: J1.3, JP16.2 (B), JP17.2 (B), JP18.2 (B), JP19.2 (B), JP20.2 (B), JP21.2 (B), JP22.2 (B), JP23.2 (B), JP24.2 (B), JP25.2 (B), JP26.2 (B), JP27.2 (B), JP28.2 (B), JP29.2 (B), JP30.2 (B)
ROW_2: J1.2, JP31.2 (B), JP32.2 (B), JP33.2 (B), JP34.2 (B), JP35.2 (B), JP36.2 (B), JP37.2 (B), JP38.2 (B), JP39.2 (B), JP40.2 (B), JP41.2 (B), JP42.2 (B), JP43.2 (B), JP44.2 (B), JP45.2 (B)
ROW_3: J1.1, JP46.2 (B), JP47.2 (B), JP48.2 (B), JP49.2 (B), JP50.2 (B), JP51.2 (B), JP52.2 (B), JP53.2 (B), JP54.2 (B), JP55.2 (B), JP56.2 (B), JP57.2 (B), JP58.2 (B), JP59.2 (B), JP60.2 (B)

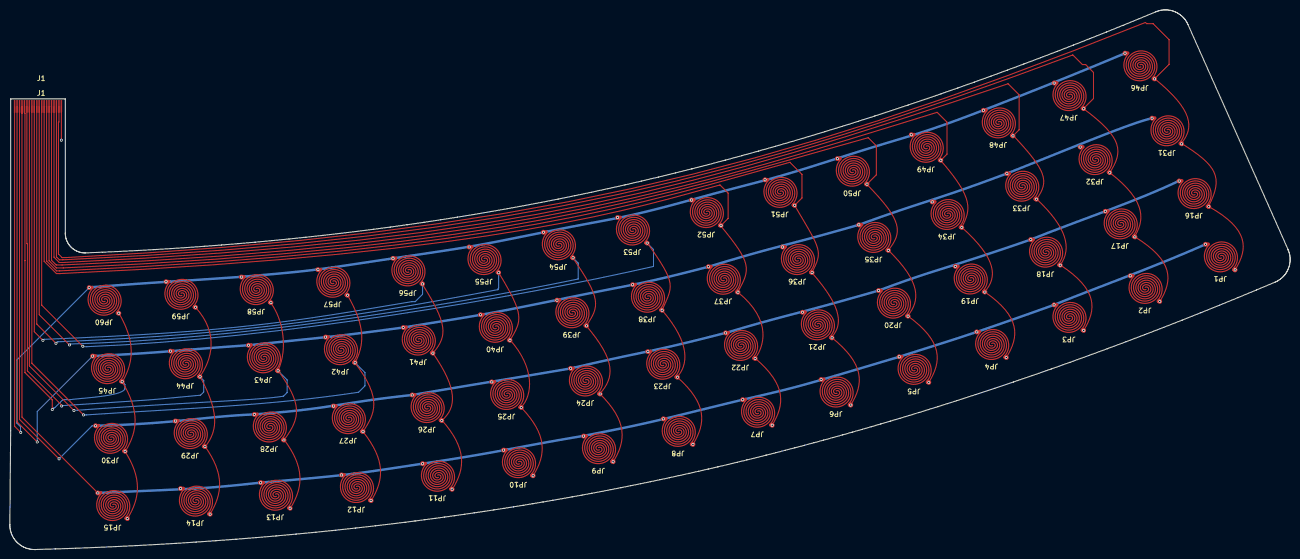
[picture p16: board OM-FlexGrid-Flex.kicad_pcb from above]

Board: 2 copper layers, 260.0 x 109.6 mm, 61 parts (0 on the bottom side), 19 nets.

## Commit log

2025-05-30 FlexGrid V1 Adjustments
    [OM-FlexGrid-Rigid-PCB-B_Cu.gbr, OM-FlexGrid-Rigid-PCB-B_Mask.gbr, OM-FlexGrid-Rigid-PCB-B_Paste.gbr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]
2025-06-18 FlexGrid V1
    [OM-FlexGrid-Flex-B_Cu.gbr, OM-FlexGrid-Flex-B_Mask.gbr, OM-FlexGrid-Flex-B_Paste.gbr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]
2025-12-19 Hardware Tweaks
    [FlexStiff.stl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]
2026-02-06 Cleanup V2-1
    [OM-FlexGrid-Flex.kicad_pcb, OM-FlexGrid-Rigid-PCB.kicad_pcb, OM-FlexGrid-Rigid-PCB.kicad_sch]
2026-04-26 V3 release - 20-pin FFC interconnect (ordered, untested)
    - Switch flex-to-rigid interconnect to Wurth 687120183722 ZIF FFC
    - Integrated stiffened FFC tail on flex (FR4, 0.20 mm, bottom side)
    - Widen FFC tail to 11.1 mm to meet Wurth 0.8 mm side margin spec
    - Add V3 gerber bundles (flex + rigid), rigid BOM CSV, V3 schematic PDF
    - Update top-level README to highlight V3 as latest revision
    - Rename schematic PDFs: Rigit -> Rigid
    - Clean up legacy V1/V2 gerber duplicates from V3 folder
    [FlexStiff.stl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]
2026-05-13 V3 bring-up complete (2026-05-13)
    Two V3 boards populated and tested end-to-end. Wurth 687120183722 FFC
    interconnect mates cleanly with the integrated stiffened flex tail
    (0.20 mm FR4 stiffener, bottom side, ~0.31 mm total -- on Wurth's
    0.30+/-0.05 mm spec). Sensor matrix scans at ~140 Hz with clean idle
    baseline and no row-sneak crosstalk (firmware fix: ground-other-rows
    scan technique). UDP telemetry confirmed reaching the desktop.
    V3 is the first revision where the flex<->rigid interconnect is no
    longer the project's main signal-quality limiter -- the breakthrough
    this revision was designed to deliver.
    Status badges bumped to 'validated'. Firmware lives at
    https://github.com/Open-Muscle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
2026-05-14 V3 README: bring-up findings + design suggestions for V4
    Document the five firmware-fixable issues we hit during V3 bring-up
    and the one open hardware finding (IO2/ROW_1 won't drive HIGH on
    board #1). Add a V4 design-suggestions section: per-row series R,
    ADC GPIO selection notes, BOOT button placement, per-cell Velostat
    patches, FFC pin-1 silkscreen markers, and test pads. None are
    required -- V3 works -- but they'd save bring-up time on the next
    revision.
2026-05-14 V3 status: PRODUCTION-QUALITY MATRIX
    v0.1.7 firmware now delivers clean single-cell press detection across
    all 60 sensors. 22% per-col carryover, decaying to noise within 3 cols.
    Direct press peak ~1100 ADC counts, idle baseline 0, scan rate 59 Hz.
    Verified with 45-cell deliberate per-cell press test (capture 1778731003).
    For the first time in the project's history, the FlexGrid matrix is
    usable as a real ML training data source. The V3 hardware revision
    (integrated stiffened FFC tail + Wurth ZIF) plus the firmware
    scan-technique stack (ground-other-rows + mux ENABLE gating + active
    row discharge + discard-first-read) together cross the threshold from
    'works' to 'good enough to ship data to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
2026-05-30 V4: baseline copy from V3, fab/backup/cache artifacts cleaned
    Starting point for V4 hardware revision. Schematically + topologically
    identical to V3 at the moment of this commit so that any subsequent V4
    commit shows up cleanly as a diff against this baseline. V3 hardware
    stays canonical for currently-fielded boards and is not modified.
    What was carried forward:
    - OM-FlexGrid-Flex/ KiCad project (sch, pcb, pro)
    - OM-FlexGrid-Rigid-PCB/ KiCad project (sch, pcb, pro, csv, step)
    - Top-level Illustrator + SVG artwork files
    - README.md (still V3-titled; bump in a follow-up commit)
    What was stripped from the V4 copy (not needed in version-N+1):
    - V3 fab outputs (Gerber dirs + zips)
    - KiCad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
    [FlexCurveGrid-cut.stl, FlexCurveGrid.stl, OM-FlexGrid-Flex.kicad_pcb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]
2026-06-07 V4 progress: SD card reader, RGB status LED, slimmer reoriented layout
    What landed in V4 (Rigid PCB):
    - microSD card socket added (data logging / model storage on-device)
    - Discrete RGB status LED (5050 common-cathode driven by 3 PWM GPIOs,
    zero quiescent current vs WS2812 family; status palette ready to
    drive from firmware)
    - Board orientation flipped for a slimmer profile that hugs the
    bracelet better; component placement reworked to clear the new
    long axis
    Production artifacts included:
    - V4 schematic (24K lines, full reroute from V3 baseline)
    - V4 PCB with new placement
    - V4 Gerber zip (OM-FlexGrid-Rigid-V4-Gerber.zip)
    - JLCPCB plugin output dir (BOM + CPL ready for upload)
    - Pi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
    [BOM-OM-FlexGrid-Rigid-PCB.csv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]
2026-06-07 V4 documentation: revision README, JLCPCB workflow, cross-version status
    Three docs land together so V4 has a real introduction for anyone
    walking up to the repo cold (future-self included):
    KiCad/OM-FlexGrid V4/README.md (replaces the V3 carryover)
    Status block, V4-vs-V3 change table, microSD wiring + part, RGB LED
    wiring + suggested status palette, layout reorientation rationale,
    footprint cleanup notes (SOD-123 standardization, 0603 enforcement),
    hand-soldered parts list, open items before fab.
    docs/JLCPCB_WORKFLOW.md (new, revision-agnostic)
    Plugin install (Bouni's repo + Install-from-File paths), 5-phase
    workflow we follow for every revision (tag LCSC, handle hand-solder,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
2026-06-07 V4 README: lock in fab strategy + complete hand-solder list
    Updates the V4 README to reflect actual decisions made during the
    final BOM pass:
    - Status bumped from "IN DESIGN" to "READY FOR FAB" with the explicit
    10-unit batch + single-side SMT + hand assembly strategy stated up
    front so anyone reading the repo cold sees the plan in one block.
    - Manufacturing section grew a "Strategy" subsection explaining the
    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
2026-06-07 V4 README: document haptic + ADC matrix caps as untested carry-forwards
    Two known concerns from the V3 bring-up history are now explicitly
    called out so a future bring-up cannot miss them:
    1. Haptic feedback circuit. Carried forward from V3 as a "just in
    case" feature. Built but never bench-tested in this configuration.
    Documented as optional / experimental, with a firmware note that
    the haptic GPIO should default low and only fire behind explicit
    opt-in to prevent surprise vibration during normal sessions.
    2. ADC matrix-row caps C12 through C15. Currently set to populate
    at the same 2.2 uF value V3 originally shipped with, which is the
    exact configuration V3 had to physi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
2026-06-07 V4 rev: ADC matrix caps 2.2uF -> 100pF, MAX16054 footprint TSOT-23-6
    Two real design changes applied to the V4 Rigid PCB this revision:
    1. ADC matrix-row caps C12, C13, C14, C15 changed from 2.2 uF
    to 100 pF. This is Option 3 from the README's "Known carry-forward
    concerns" section. New LCSC: C14858 (100 pF 0603, Basic tier).
    RC time constant with the 10 kohm row pulldown drops from ~22 ms
    to ~1 us, well below the per-column ADC dwell time. Resolves the
    column-to-column bleed problem V3 saw with the 2.2 uF parts
    without sacrificing high-frequency noise filtering.
    2. MAX1 (MAX16054 soft-power controller) footprint swapped from
    SOT-23-6 to TSOT-23-6. The LCSC part C79401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
    [BOM-Human-OM-FlexGrid-Rigid-PCB.csv, BOM-OM-FlexGrid-Rigid-PCB.csv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]
2026-06-07 V4 README: mark ADC cap decision + MAX16054 footprint swap as resolved
    Reflects the design changes that just landed in a8c1de1:
    - ADC matrix-row caps section is now RESOLVED at 100 pF (LCSC
    C14858). Three-option analysis preserved for posterity but the
    choice is explicit. The "decide C12-C15 fate" item is removed
    from the still-open checklist.
    - Footprint cleanup list gains the MAX1 (MAX16054) SOT-23-6 ->
    TSOT-23-6 swap with the rationale, alongside the value cleanup
    from "~" to "MAX16054".
    - Pre-fab checklist's resolved-this-pass section gets two new
    checked items reflecting the cap change and the MAX1 footprint
    fix. Still-open section now has 4 items left (mechanical check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
2026-06-07 V4 Flex: Fusion 360 -> KiCad SVG prep script + ready-to-import outlines
    Two Fusion 360 / Shaper Origin exports needed shape massaging before
    they could go into KiCad on the right layers:
    FFC-Stiffener_Faces.svg 1.2 x 0.8 cm rectangle, stiffener for
    the FFC tail
    V4CurveCutout_Faces.svg ~10.8 x 28.3 cm curved outline of the
    entire flex PCB body
    scripts/prep_flex_svgs.py does the following:
    1. Parses both SVGs, applies the embedded transform matrix into
    the path data so the polylines are in plain user-space coords.
    2. Samples arcs into short line segments (128 per arc for the
    curvy body) so the rotation + bbox math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
2026-06-07 V4 Flex: cutout rotated +67.6 deg to match horizontal-bracelet layout
    User feedback: my auto-rotation laid the banana shape on its vertical
    axis (28cm tall, 10cm wide), but the actual target orientation is
    horizontal -- body lying on its side, FFC tail at bottom-left, body
    curving up to the right end. That matches how the flex actually wraps
    around the user's forearm in the bracelet form factor.
    Re-ran prep_flex_svgs.py with --rotate-cutout 67.615 (which is
    -22.385 + 90, the auto-detected angle plus a 90 deg flip to lay the
    body horizontal). Result is now 28.84 cm wide x 10.33 cm tall with the
    FFC tail's left edge perfectly vertical, matching the reference image
    the user shared.
    If the FFC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
2026-06-07 V4 Flex: pick up new Fusion export with 10.5mm FFC tail width
    User re-exported from Fusion 360 after fixing the FFC tail width
    from 11.1mm to 10.5mm (the correct value per the Wurth 687120183722
    datasheet). The new export landed as FFC-Stiffener.svg and
    V4CurveCutout.svg (without the _Faces suffix Fusion was using
    before).
    Script change: prep_flex_svgs.py now prefers the non-suffixed
    filename when it exists, falling back to the _Faces names. This
    means future re-exports overwrite seamlessly.
    Re-ran prep with --rotate-cutout 67.615 (same as the previous
    working horizontal-banana orientation):
    Stiffener: now 1.05 x 0.8 cm (was 1.2 x 0.8) -- matches the
    10.5mm FFC tail width.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
2026-06-09 top README: surface V4 in-development status + cross-revision links
    Brings the repo landing page in line with the V4 work that just
    landed publicly:
    - Header gets a second status badge for V4 (in development) alongside
    the existing V3 (stable) badge.
    - "Latest revision" section becomes "Current revisions" with V4 and
    V3 blocks side by side. V4 block summarizes what's new (microSD,
    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
2026-06-09 V4 README: link reviewable PDFs + 5 PDF files added
    User asked to make the schematic and PCB PDFs discoverable from the
    V4 README so people can review the design without opening KiCad.
    Adds a "Design documents (PDFs)" section near the top of the README,
    right after the status block, with click-through links to:
    Rigid PCB:
    FlexGridV4-Rigid-Schematic.pdf full schematic, all sheets
    FlexGridV4-Rigid-PCB.pdf board layout
    Flex PCB:
    FlexGridV4-Flex-Schematic.pdf sensor matrix schematic
    FlexGridV4-Flex-PCB.pdf flex layout including the FFC tail
    FrontCopper_SolderMask.pdf Velostat cell exposure overlay
    Same section includes a one-paragraph summa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
2026-06-09 Add FlexGrid V4 design with onboard SD card; clean up backups
    V4 rigid and flex PCB design. Adds an onboard microSD card so the band can log capture sessions standalone, without a tethered PC. V4 3D and animation assets (Blender, glTF, STEP) are tracked via Git LFS.
    Also stop versioning KiCad and Blender auto-backups (*-backups/, *.blend[0-9]) and remove the old backup archives.
    Suggested-by: Kyle.T.Y <64039282+HeatRIderHR@users.noreply.github.com>
    [5033981892.stp, 687120183722 (rev1).stp, ESP32-S3-WROOM-1.STEP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]
2026-06-12 V4 ordered: as-fabricated state + cost breakdown in README
    Submitted 10 units to JLCPCB on 2026-06-12 for single-side SMT.
    Total landed cost $341.84 ($34/board JLC + ~$12/board hand-solder
    add-ons). Captures the as-ordered KiCad files and the generated
    flex Gerber set so future revisions can diff cleanly against what
    the first 10 physical boards came from.
    README:
    - Status block bumped from "READY FOR FAB" to "ORDERED, in fab"
    - New "Cost breakdown" section with real per-board numbers from
    the JLC checkout and rough qty-10 prices for the hand-solder
    add-ons (ESP32 module, microSD, USB-C, mux, FFC connector,
    through-hole headers, BOT-side passives) plus external parts
    (OLED display,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
    [BOM-OM-FlexGrid-Rigid-PCB.csv, FlexGridV5.blend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]
2026-06-23 V4 Rigid PCB: fix USBLC6 pinout + expand JLC-assembled BOM
    USBLC6 ESD chip fix
    -------------------
    Swap the VBUS and GND power-flag connections on the USBLC6-2SC6
    footprint in the schematic. Earlier revision wired pin 2 to VBUS
    and pin 5 to GND, but the actual chip pinout is pin 2 = GND and
    pin 5 = VCC. Result on the first populated V4 board was that the
    USB enumerated VBUS (Windows chime) but the data lines were
    clamped to garbage by the now-forward-biased internal ESD diodes,
    so no COM port was assigned and esptool could not sync.
    Workaround on the first board was to rotate the USBLC6 180 degrees
    during placement (SOT-23-6 footprint is symmetric, so the I/O pin
    pairs route correctly eithe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
    [BOM-OM-FlexGrid-Rigid-PCB.csv, FlexGridV5.blend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]
2026-06-24 docs(V4): refresh README to reflect bring-up state
    V4 boards arrived 2026-06-23 and are running V4 firmware end-to-end.
    README was still saying 'In fab at JLCPCB. Not yet brought up.'
    Updates:
    - Top status block now reads BROUGHT UP 2026-06-23, summarizes the
    two HW bugs found during bring-up.
    - New 'Bring-up findings' section covers the USBLC6 pinout reversal
    (schematic-fixed; existing boards work with 180-degree rotation)
    and the TOKMAS IMU vs InvenSense substitution (driver workaround
    shipped; recommend C1850418 for next fab).
    - Pre-fab checklist 'Still open' items collapsed to what is actually
    still open (3D fit check, next-fab BOM changes, collaborator
    distribution). Bring-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
2026-06-24 docs(V4): add build video link to the README
    Link the Unboxing & Setup video (hand-assembly + bring-up) from the V4 README.
2026-11-03 V4-2 Rigid PCB: USB presence sensing, vias out of pads, USB pair routing
    Schematic rev V4 -> V4-2:
    - VBUS sense divider R19 (10k) / R20 (100k) to IO39 on net VBUS-STAT, so
    firmware can tell when USB is plugged in (the MAX16054 latch keeps the
    board on while VBUS is present). Divider values still to be finalised:
    as drawn the node sits near 4.5 V.
    - R21 (100k) pull-down on PWR_OFF (Q3 gate, IO45).
    - Charger PROG note corrected: R4 2k sets 500 mA.
    Layout:
    - 28 of the 29 vias that sat inside SMD pads moved next to their pads;
    one remains on Q3 pad 2. Addresses #3.
    - D+/D- between the USBLC6 and the ESP32 module re-routed together
    (16.4 / 19.6 mm, was 15.6 / 34.5 mm). Addresses #4.
    -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
2026-11-03 docs: V4 is validated and current; describe revision V4-2
    - Top README, V4 README and REVISIONS.md: V4 marked validated and current
    (fabbed 2026-06, brought up 2026-06-23, two bands shipped as the first
    starter kit 2026-10 on firmware v4.0.1); V3 becomes the previous revision.
    - New V4-2 section: VBUS sensing circuit and its open value check, vias out
    of pads (#3), USB pair routing (#4), what is still not regenerated
    (BOM/CPL/Gerbers), DRC summary.
    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

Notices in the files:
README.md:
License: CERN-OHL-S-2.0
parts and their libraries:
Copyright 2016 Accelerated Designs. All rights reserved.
